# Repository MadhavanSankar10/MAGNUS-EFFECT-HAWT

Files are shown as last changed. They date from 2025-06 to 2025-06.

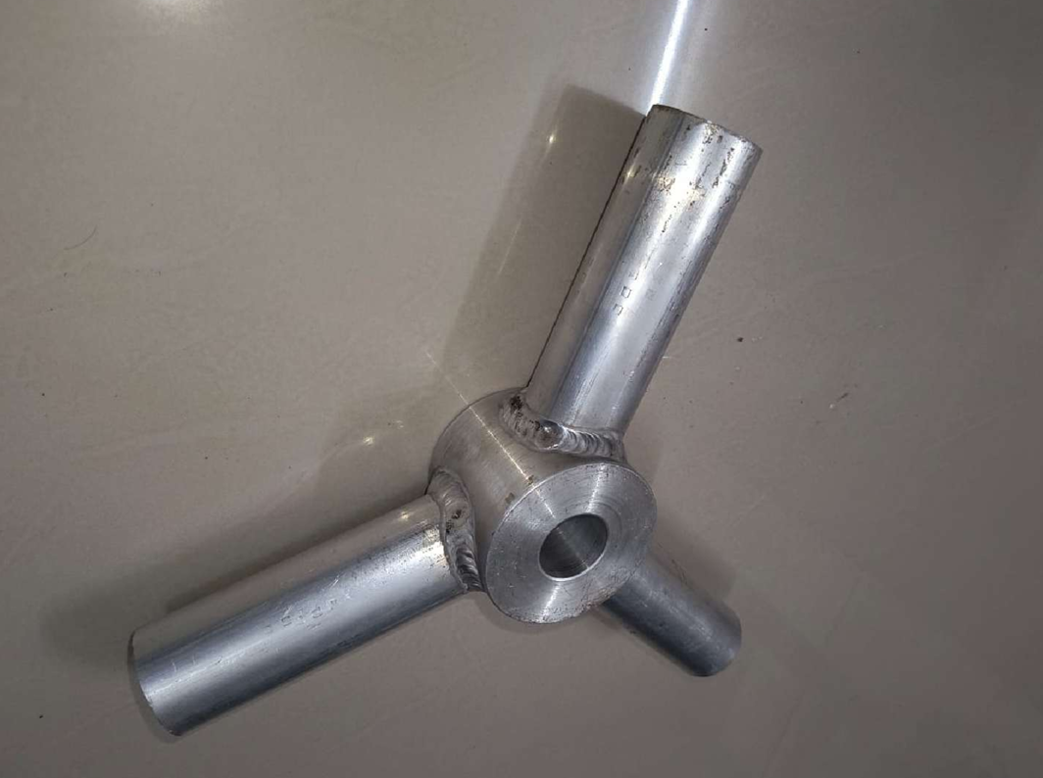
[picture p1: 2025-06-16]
pictures/assembly and components/Screenshot 2025-06-16 195948.png

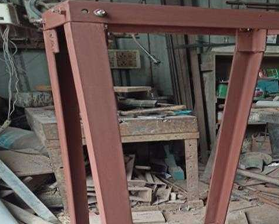
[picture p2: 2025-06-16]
pictures/assembly and components/Screenshot 2025-05-29 222510.png

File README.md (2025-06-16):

# 🌪️ Magnus Effect Horizontal Axis Wind Turbine (HAWT)

This project presents the design, simulation, and testing of a **horizontal-axis wind turbine** (HAWT) utilizing the **Magnus Effect** to enhance aerodynamic lift and torque generation.

---

## 📌 Project Overview

The turbine is designed with rotating cylindrical blades to exploit the Magnus Effect, leading to improved efficiency even at low wind speeds. Simulations were conducted using **ANSYS Fluent** (for CFD analysis)

---

## 🛠️ Tools & Technologies Used

- 💻 **ANSYS Fluent** – Dynamic CFD simulation
- 🧰 **NX CAD** – Mechanical design
- ⚡ **Permanent Magnet Generator** – Power output analysis
- 📸 Field testing and experimental validation

---

## 🔍 Design Specifications

| Parameter | Value |
|---|---|
| Rotor Diameter | 3.35 m |
| Blade Diameter | 0.325 m |
| Blade Length | 1.5 m |
| Tip Speed Ratio (TSR)  | 3.8 |
| Wind Speed | 5–6 m/s |
| Angular Velocity | 152 rad/s |
| Torque Output | ~8.12 Nm (CFD)  |

---

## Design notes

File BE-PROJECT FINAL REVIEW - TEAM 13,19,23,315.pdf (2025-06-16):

## PROJECT PRESENTATION

1

# POWER GENERATION FROM A SMALL WIND TURBINE

### HORIZONTAL AXIS MAGNUS EFFECT TURBINE

PROJECT SUPERVISOR

DR.K.SOORYA PRAKASH M.E.,Ph.D., H.O.D/Assistant Professor
Dept of Mechanical Engineering Anna university Regional campus Coimbatore-641046

PROJECT MEMBERS

### 1. Kaviyaselvan .K - 710021114013

2. Madhavan .S | - 710021114019
3. Monish .R | - 710021114023

### 4. Naveenkumar .A - 710021114315

DEPARTMENT OF MECHANICAL ENGINEERING

## NEED FOR RENEWABLE ENERGY

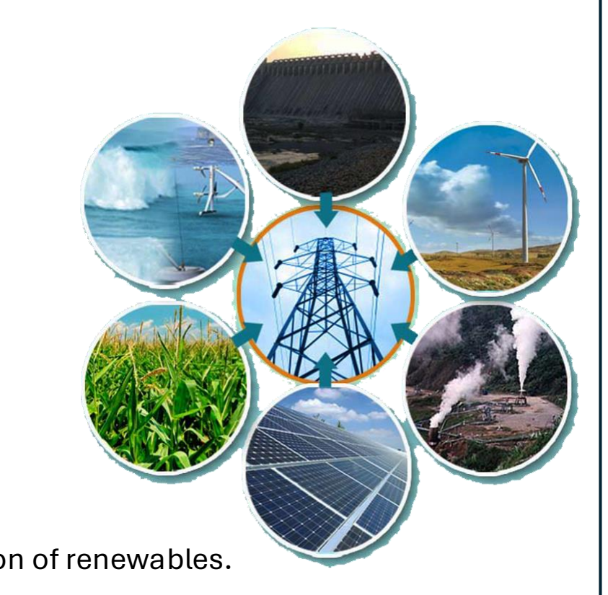
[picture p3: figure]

2

Environmental Concerns
- Fossil fuels cause air pollution, global warming, and climate change.
- Renewable energy produces zero greenhouse gas emissions during operation. Depletion of Fossil Fuels
- Coal, oil, and natural gas are finite and rapidly depleting.
- Energy demand is rising globally.
Cost & Energy Security
- Fossil fuel prices are volatile due to geopolitical and supply chain issues.
- Renewables provide stable, domestic energy sources.
Global Shift Toward Clean Energy
- Initiatives like Mission Innovation, Net Zero by 2050, and UN SDGs drive adoption of renewables.

### ABSTRACT

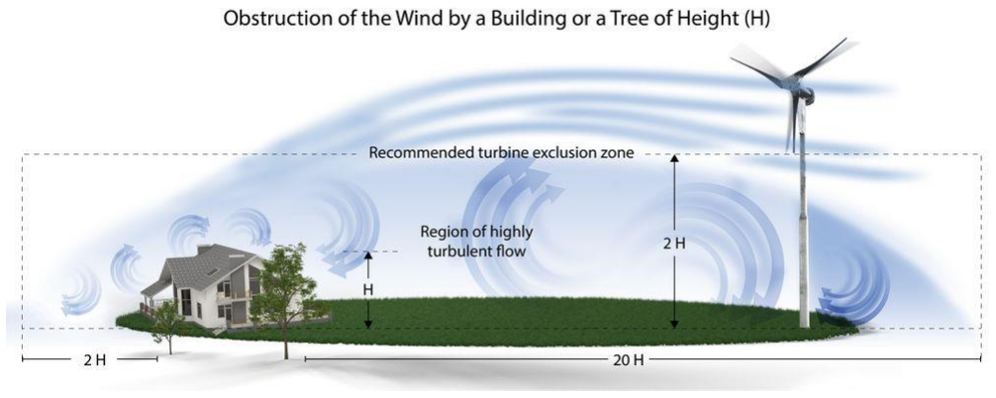
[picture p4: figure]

3

- The project focuses on renewable energy generation using a small-scale wind turbine.
- Aims to harness wind energy effectively through a Magnus-effect-based turbine.
- Utilizes rotating cylindrical blades instead of traditional airfoil blades to improve performance at low wind speeds.
- Designed and analyzed using Siemens NX for modeling and ANSYS Fluent for CFD simulations.
- The prototype was fabricated and tested in real wind conditions, showing promising voltage output even at low wind speeds.

### OBJECTIVE

4

- To design and develop a horizontal axis Magnus wind turbine for small-scale power generation.
- To convert wind energy into electrical energy using the Magnus effect with rotating cylindrical blades.
- To reduce dependency on fossil fuels and promote the use of clean, renewable energy sources.
- To evaluate turbine performance under low to moderate wind speeds, making it suitable for rural and urban applications.
- To carry out CFD analysis and field testing for validating the design efficiency.
- To create a cost-effective prototype with potential for future scale-up and real-world implementation.

### GOALS

### WHAT IS MAGNUS EFFECT ?

5

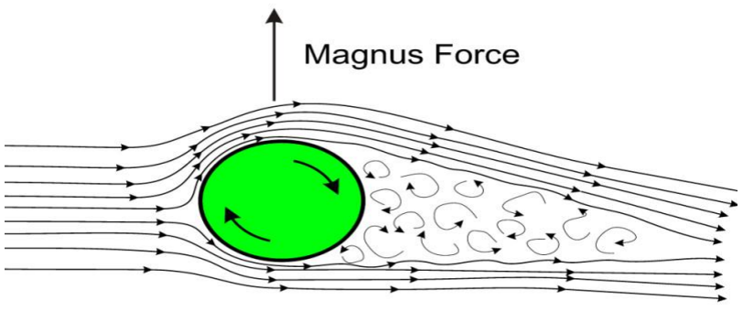
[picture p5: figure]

- The Magnus Effect is a physical phenomenon where a spinning object in a fluid (like air) experiences a lift force perpendicular to the direction of flow.
- It occurs due to pressure differences created by the variation in flow speed around the rotating surface.
- Common in sports: seen in the curved path of spinning balls (football, baseball, golf).

### MAGNUS EFFECT WIND TURBINE

6

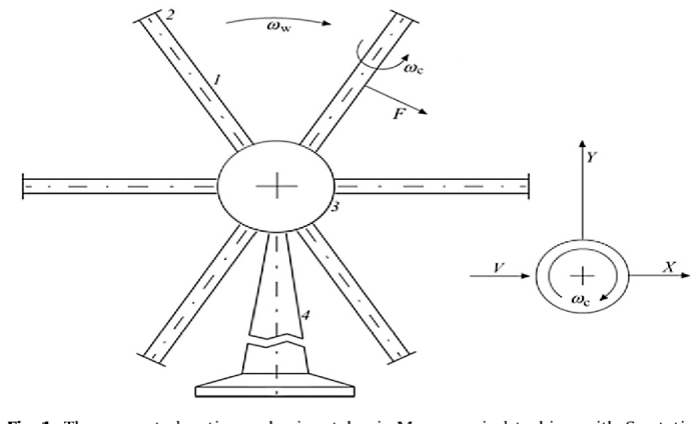
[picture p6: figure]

- Replaces traditional airfoil blades with rotating cylindrical blades.
- These rotating cylinders generate lift using the Magnus effect, which creates torque to drive the turbine shaft.
- Particularly effective in low wind speed conditions, where traditional turbines struggle.
- Offers potential for higher efficiency, lower noise, and better performance in urban or low-wind regions.

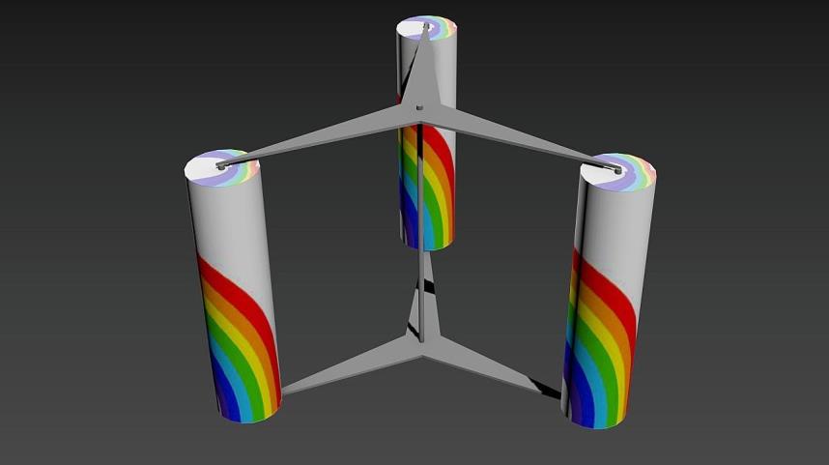
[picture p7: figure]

### DESIGN TOOLS USED

7

### 1. Siemens NX (CAD Software)

- Used for 3D modeling and assembly of turbine components.
- Designed parts such as blades, hub, shaft, and base.
- Enabled precise dimensioning and part alignment.
- Supported mechanical validation before fabrication.

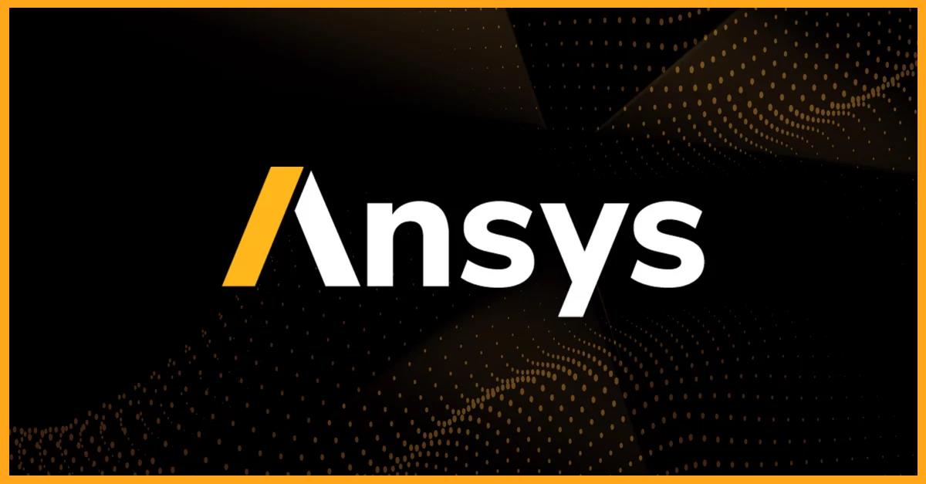
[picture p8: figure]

### 2. ANSYS Fluent (CFD Analysis)

- Used for Computational Fluid Dynamics (CFD) simulations.
- Analyzed airflow, pressure distribution, and velocity contours.
- Helped visualize Magnus effect behavior on rotating cylinders.
- Ensured design efficiency before physical testing.

### TURBINE BLADE DESIGN

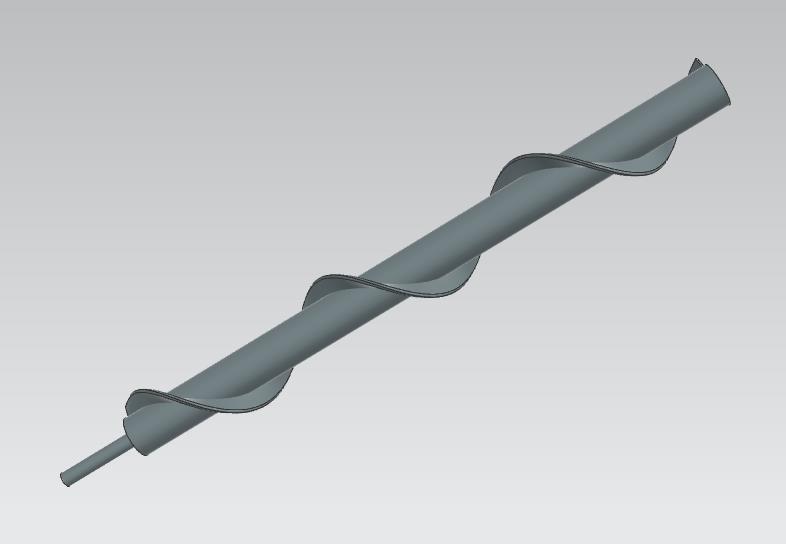
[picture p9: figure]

8

- Three cylindrical blades made of PVC for strength and lightweight.
- Spiral profile added using FRP (Fibre Reinforced Plastic) to enhance surface roughness and lift via Magnus effect.
- Connected to an 18 mm shaft at each end for rotation and torque transmission.

Key Dimensions:
- Blade Length: 750 mm
- Blade Diameter: 50 mm
- Diameter with Spiral: 90 mm
- Spiral Pitch: 90 mm

### HUB & BASE DESIGN

9

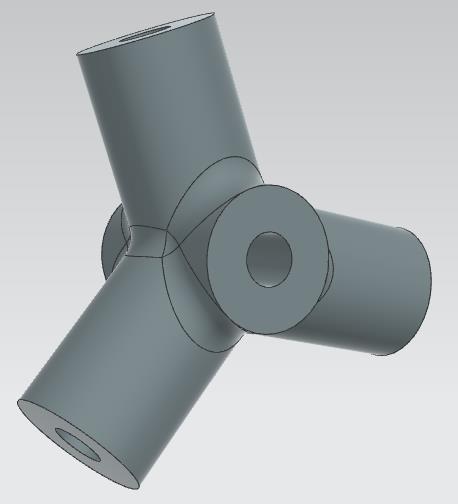
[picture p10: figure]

Hub:
- Hub connects all three blades to the main shaft.
- Includes bearings for smooth rotation and load transfer.
- Precisely machined for aerodynamic alignment. Base:
- Mild steel base supports the entire turbine structure.
- Designed for stability against wind loads and vibrations.
- Tapered form for better center of gravity and mounting.

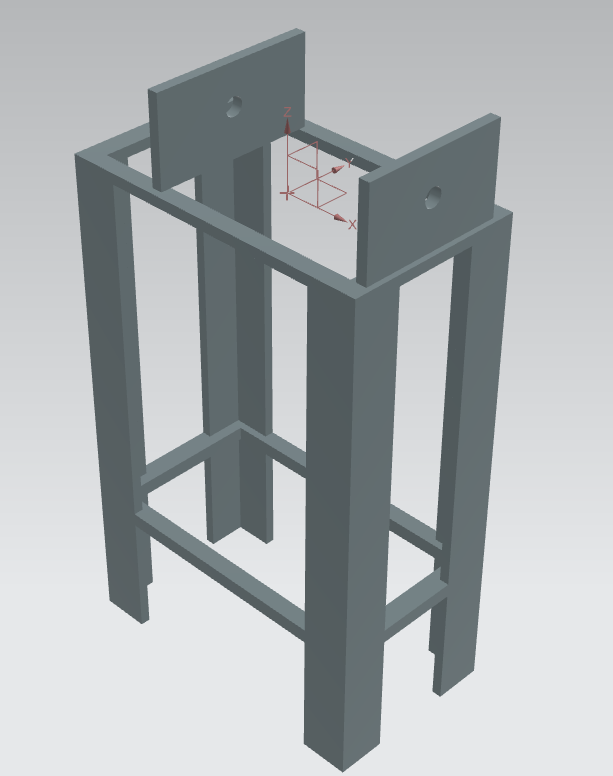
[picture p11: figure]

Base Dimensions:
- Height: 1270 mm
- Top area: 460 mm × 260 mm
- Bottom area: 460 mm × 520 mm

### SHAFT DESIGN

10

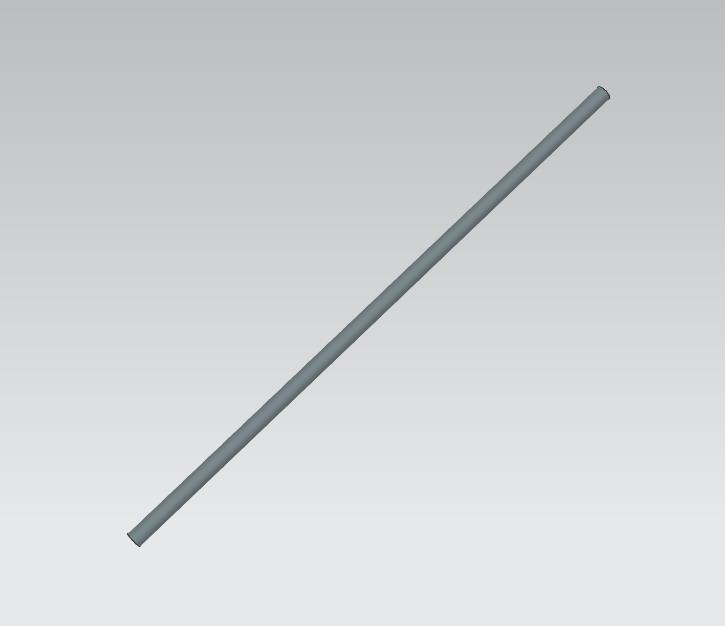
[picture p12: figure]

- Transfers rotational energy from blades to the Permanent Magnet Generator (PMG).
- Made of Mild Steel (MS) for strength and durability.
- Connected securely to hub on one end and generator on the other.

Key Specifications:
- Shaft Diameter: 25 mm
- Shaft Length: 850 mm

### FULL ASSEMBLY

11

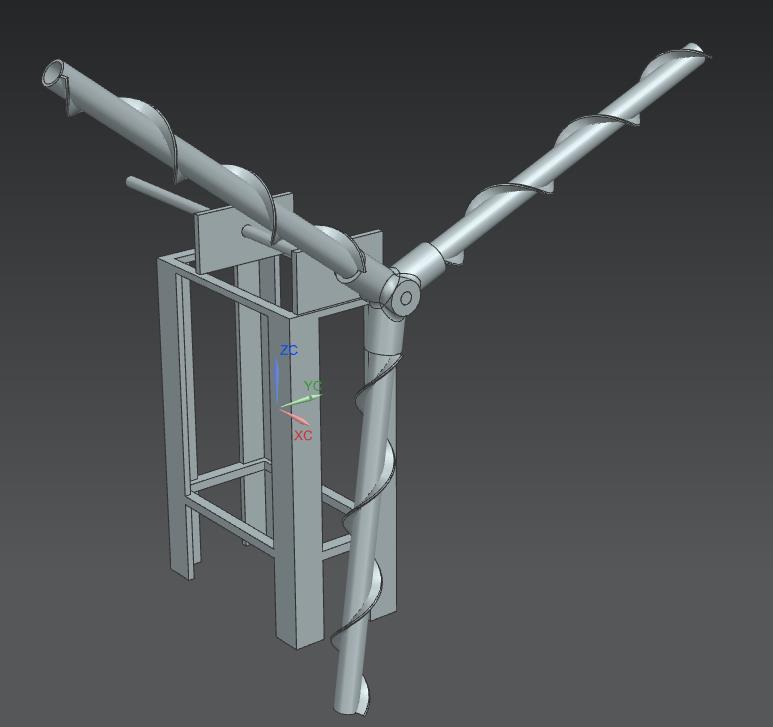
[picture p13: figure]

- Complete 3D model designed in Siemens NX.
- Includes blades, hub, shaft, base, and generator housing.
- Ensures correct alignment and fitment before fabrication.
- Used as reference during physical assembly and testing.

### MOTION SIMULATION

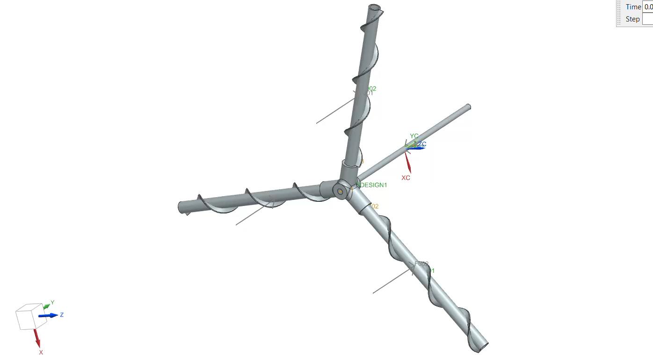
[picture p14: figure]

12

### CFD SETUP – GEOMETRY & MESH

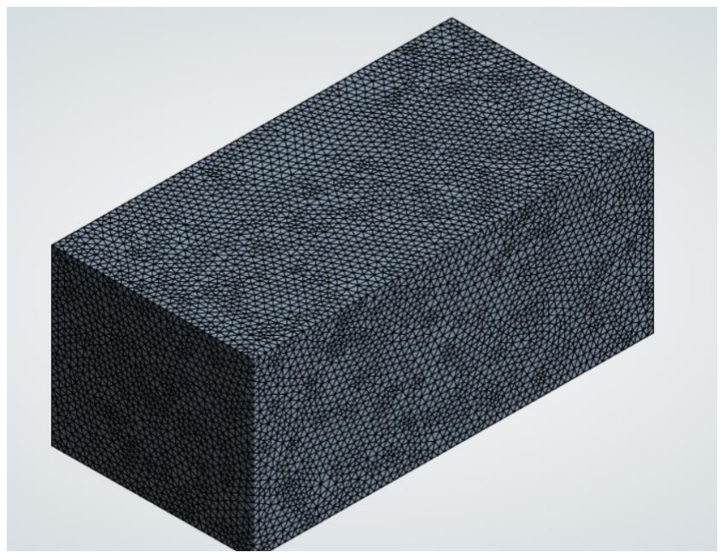
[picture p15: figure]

13

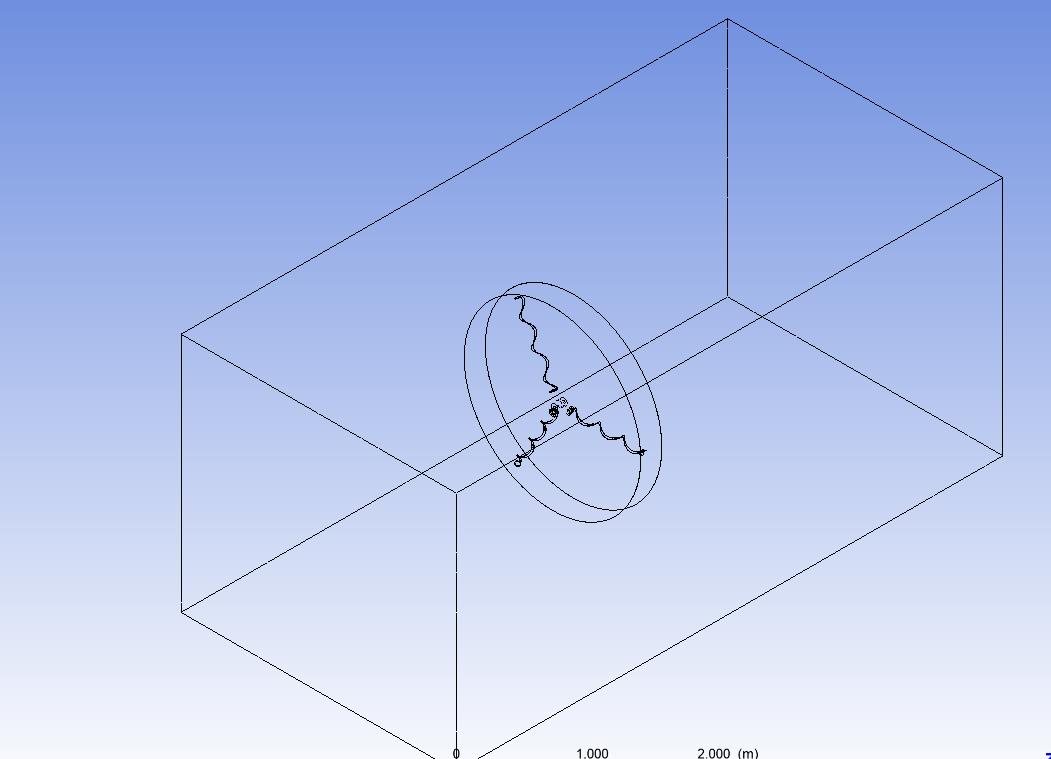
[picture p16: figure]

- 3D model exported from Siemens NX into ANSYS Fluent.
- Fluid domain created around rotating blades.
- Used Moving Reference Frame (MRF) for rotational simulation.
- Fine mesh near blade surface; coarse mesh far from the body.
- Boundary Conditions:
- Inlet: Wind velocity (5 m/s)
- Outlet: Pressure outlet
- Blade: Rotating wall (Magnus effect)

### CFD RESULTS

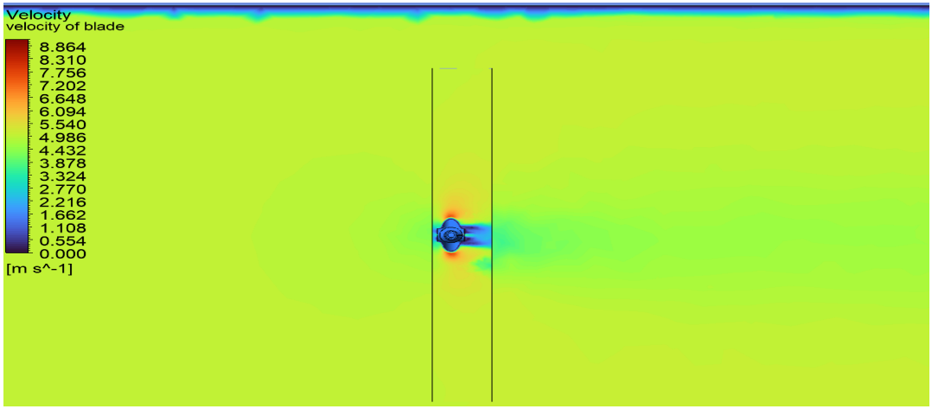
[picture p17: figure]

14

Velocity Contour:
- Shows higher velocity on one side of rotating cylinder and lower on the other.
- Confirms Magnus effect in action → Lift and torque generated.

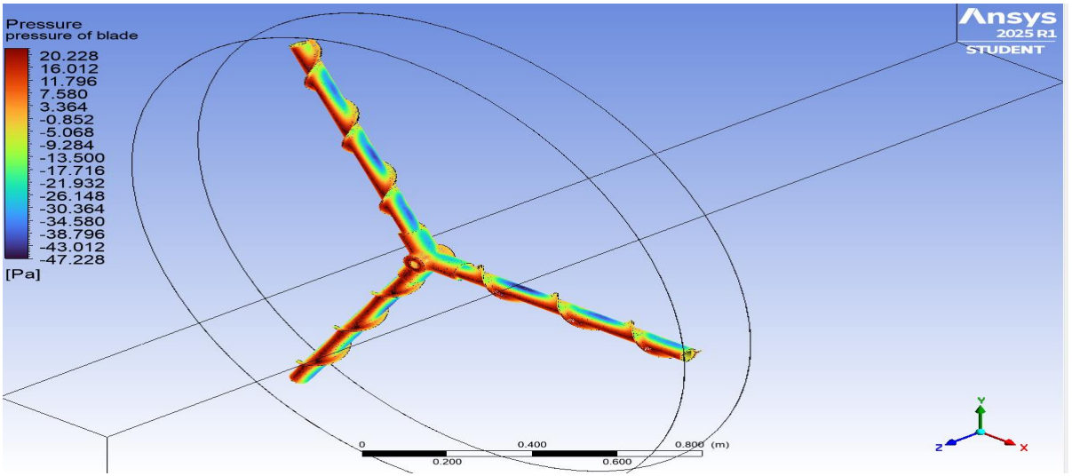
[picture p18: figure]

15

Pressure Contour:
- Low pressure where flow velocity is high.
- Pressure difference across cylinder drives rotation.

16

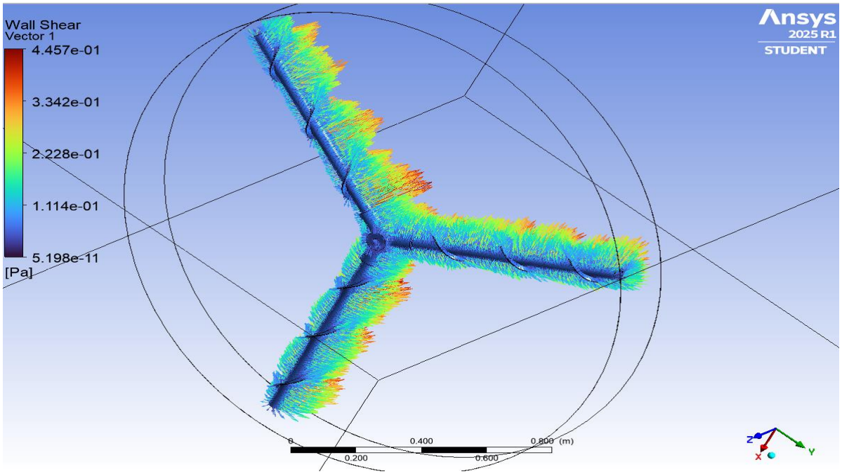
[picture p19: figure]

17

### FABRICATION PROCESS OVERVIEW

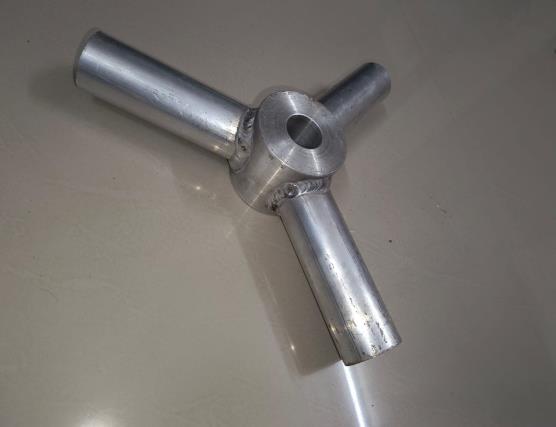
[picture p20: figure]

18

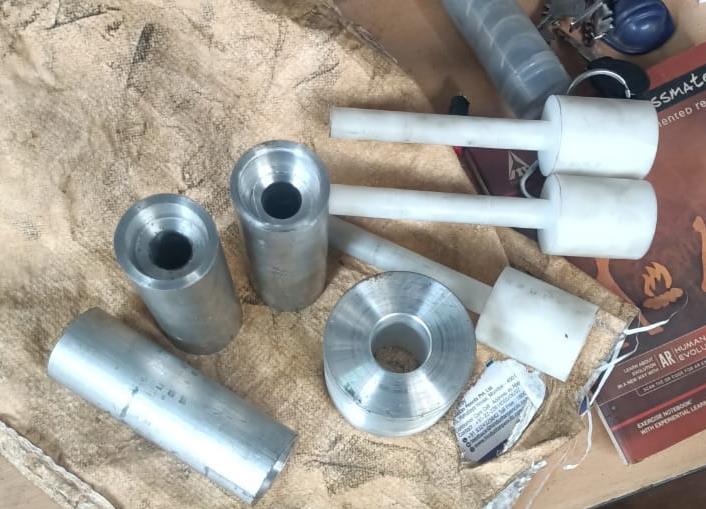
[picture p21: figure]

- Fabrication involved cutting, drilling, welding, and assembly of components.
- Main Steps:
- Helical cylinder blades made using PVC and FRP spiral wrapping.
- Mild steel base constructed with L-angles for stability.
- Hub and shaft machined and aligned using SKF bearings.
- Components were assembled on a welded support frame.
- Ensured proper alignment for smooth rotation and torque transfer.

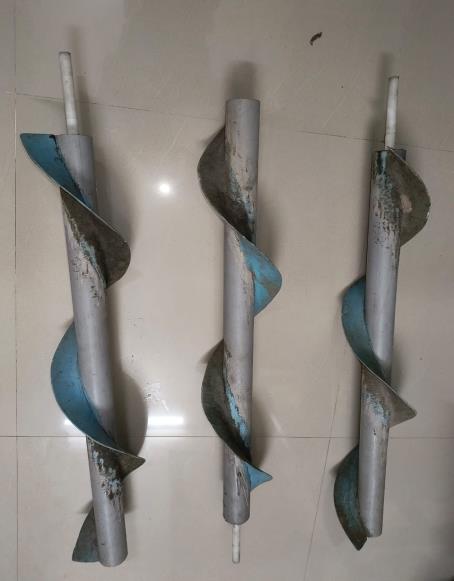
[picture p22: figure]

### FABRICATION PROCESS OVERVIEW

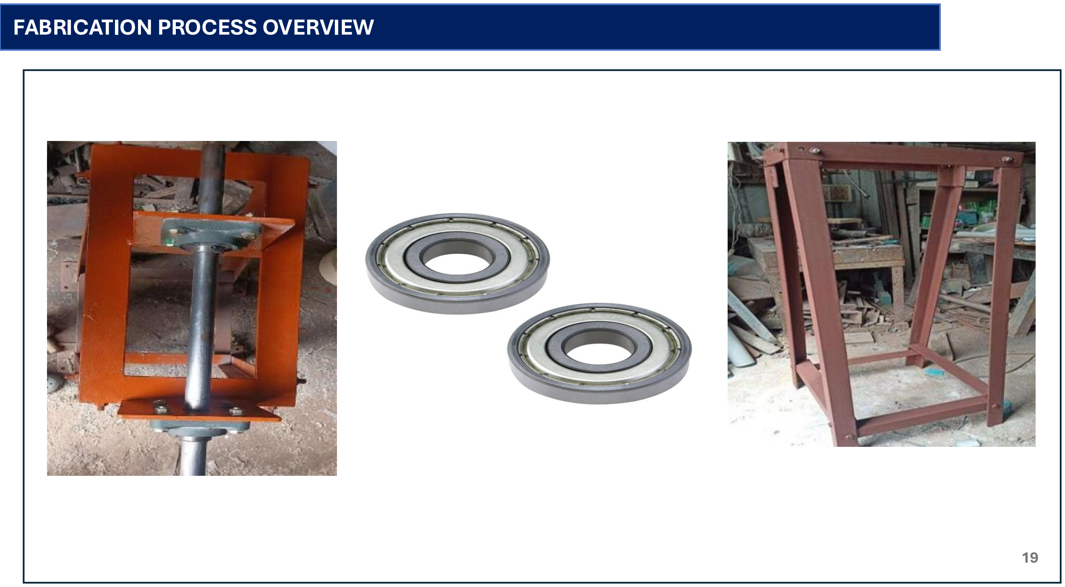
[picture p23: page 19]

19

### ASSEMBLY

20

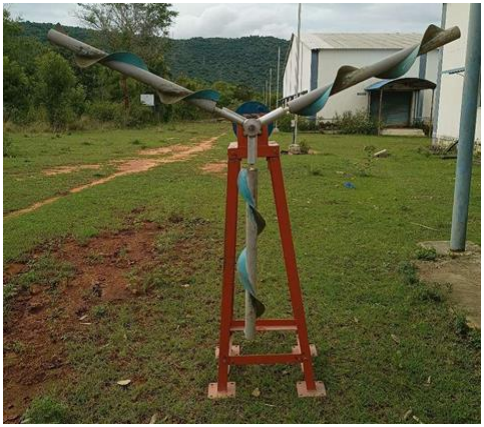
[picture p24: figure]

- Final prototype was assembled after fabricating individual components.
- All parts were aligned for smooth rotation and load transfer.
- Major components in the assembly:
- Rotating blades (PVC + FRP spiral)
- Hub with SKF bearings
- Mild steel base frame
- Central shaft connecting rotor to generator
- Permanent Magnet Generator (PMG) mounted at the rear

### MATERIALS USED

21

Component | Material
Blades | PVC (Cylinder) + FRP (Spiral layer)
Base Frame | Mild Steel (MS)
Shaft | EN8 Steel
Bearings | SKF Bearings
Generator | Neodymium Permanent Magnet Generator (PMG)
Hub | Aluminum rod
Fasteners | Standard steel bolts and nuts

### PERMANENT MAGNET GENERATOR (PMG)

22

- Converts mechanical rotation into electrical energy.
- Uses neodymium magnets for strong, efficient field generation.
- No external power required – self-exciting design.
- High efficiency (>90%) and low starting torque (0.1 Nm).

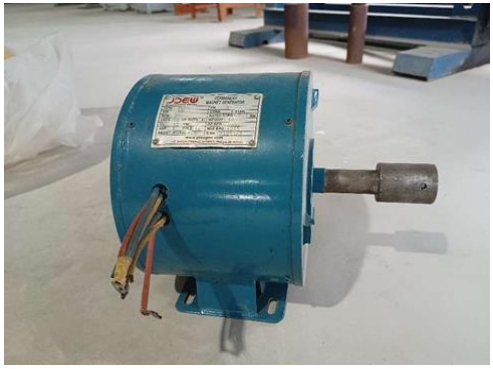
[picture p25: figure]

- Specs:
- Power: 200W | Voltage: 12V (3-phase)
- Poles: 30 | RPM: 200
- Shaft: EN8 | Material: Cast Iron
- Insulation Class: H | Protection: IP54

### Testing & Results – Field Test

23

- Conducted open field tests under natural wind conditions.
- Instruments used:
- Anemometer (Wind speed)
- Tachometer (Rotor RPM)
- Voltmeter (DC output)
Wind Speed (m/s) | RPM | Voltage (V)
2.8 | 120 | 3.2
3.5 | 150 | 4.1
4.2 | 180 | 5.0
5.0 | 210 | 6.2

### CONCLUSION & FUTURE SCOPE

24

Conclusion:
- Successfully designed, fabricated, and tested a Magnus-effect-based wind turbine.
- Demonstrated reliable low-speed wind energy generation.
- CFD analysis validated aerodynamic efficiency.

Future Scope:
- Integrate energy storage or grid-tie inverter for real-world use.
- Optimize blade surface (fins/texture) for better torque.
- Scale up for community or rooftop-level installations.

### Q&A / THANK YOU

25

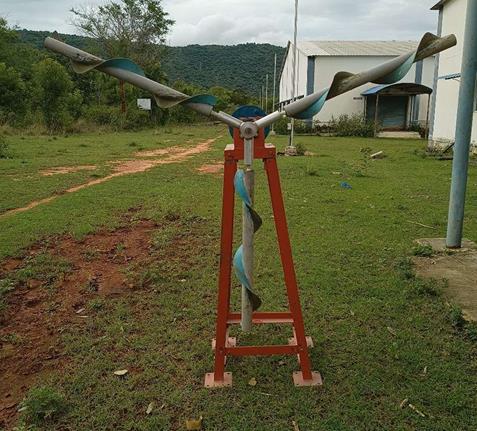
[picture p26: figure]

“Thank you for your attention!”

Any Questions?

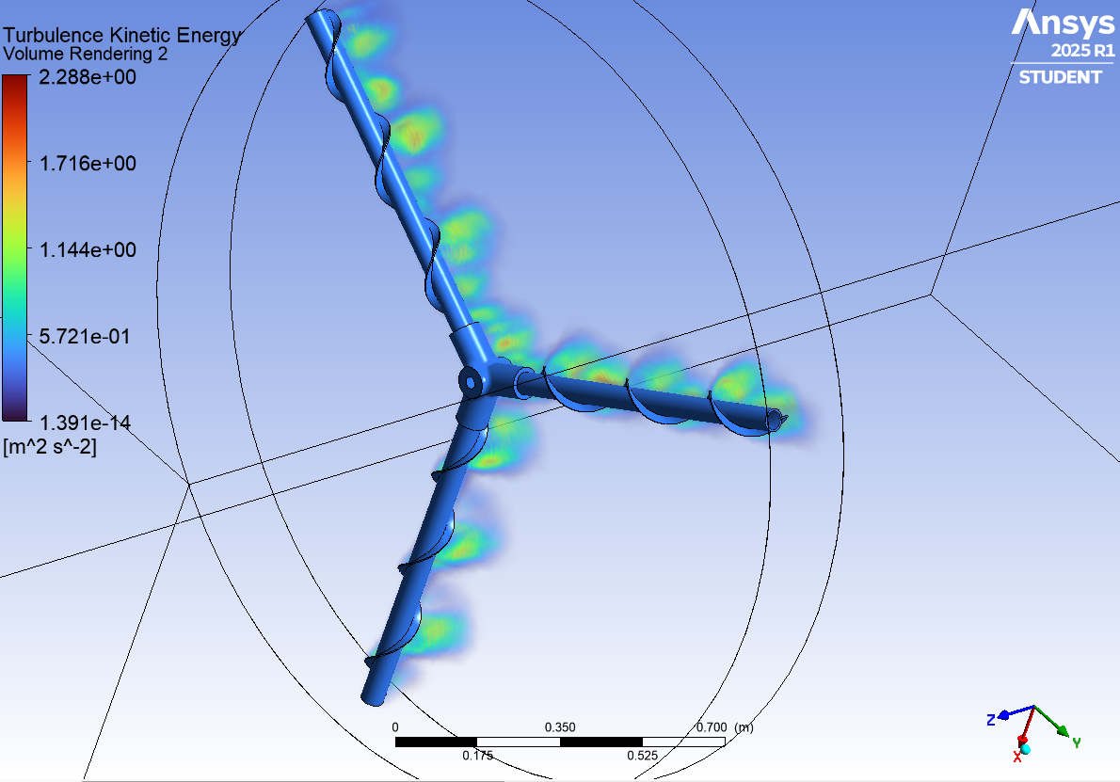
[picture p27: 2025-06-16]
pictures/cfd images/Screenshot 2025-05-29 141721.png

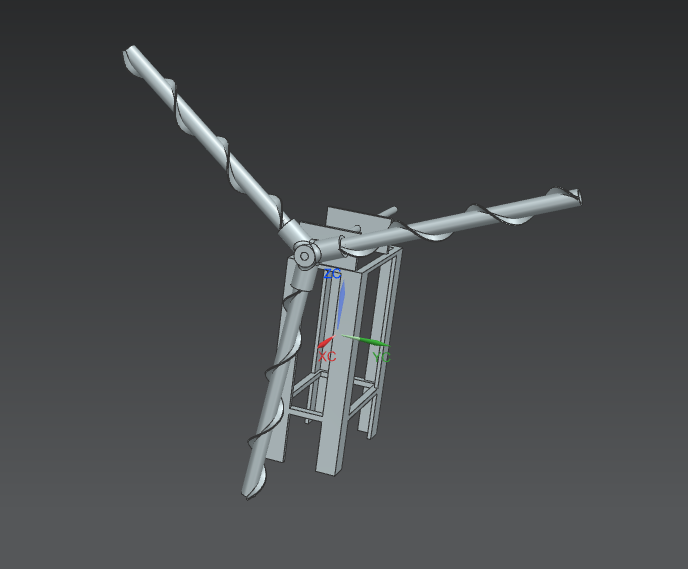
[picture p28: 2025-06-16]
pictures/cad images/Screenshot 2025-05-29 114957.png

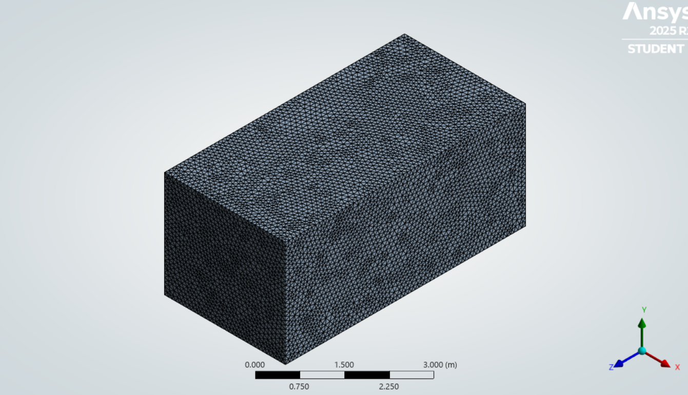
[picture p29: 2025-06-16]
pictures/cfd images/Screenshot 2025-05-29 145258.png

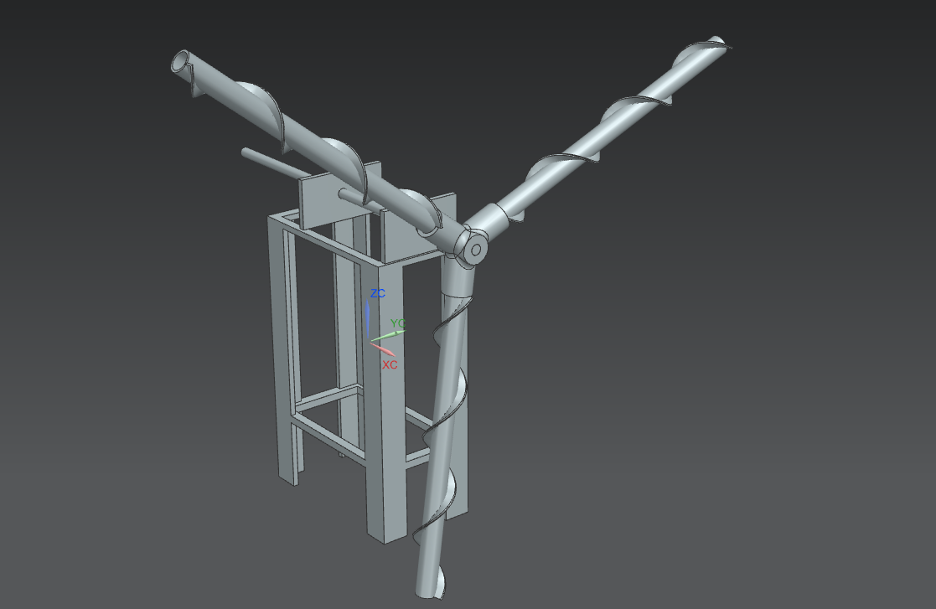
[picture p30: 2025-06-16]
pictures/cad images/Screenshot 2025-05-29 115017.png

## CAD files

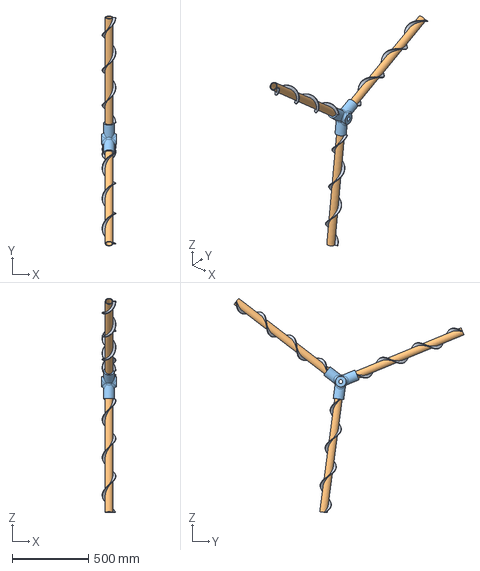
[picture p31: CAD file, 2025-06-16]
assembly files/assembly1.stp
100.0 x 1510.0 x 1407.8 mm
blade 2 de x 3
hubdesign1

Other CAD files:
assembly files/assembly1.prt
cad files/blade 2 de.prt
cad files/blade 2 de61.prt
cad files/blade 2 de_MODEL.prt
cad files/hubdesign1.prt
cad files/hubdesign160.prt
cad files/hubdesign1_MODEL.prt
cad files/model whole.prt
cad files/shaft.prt
cad files/stand.prt
